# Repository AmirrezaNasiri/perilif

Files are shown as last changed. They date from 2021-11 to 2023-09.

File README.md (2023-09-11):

# Perilif: Period Pain Reliever 🌸

<p align="center">
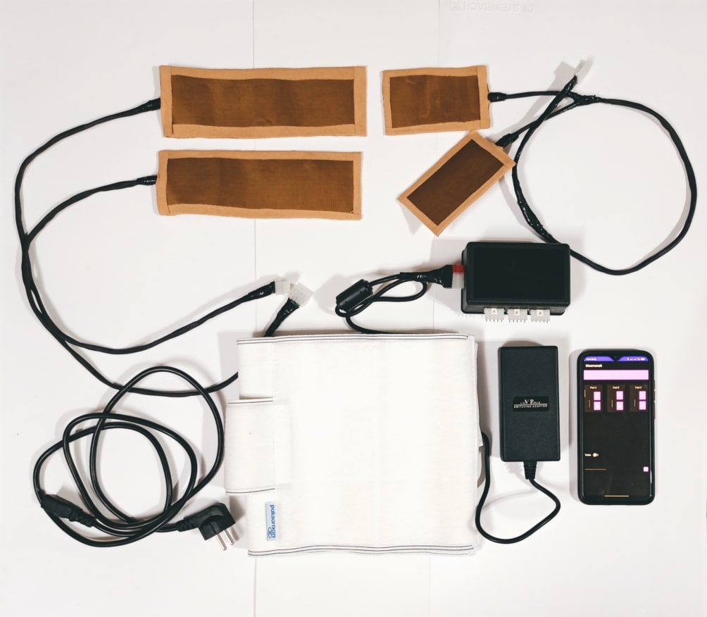
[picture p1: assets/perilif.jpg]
Perilif Image
  
</p>

Welcome to Perilif! This is a delightful, heat pad-based buddy designed to soothe menstrual cramps and IBS pain. Built with love on Arduino, it's paired with a cute Android app for easy control.

**Now, a little secret 🤫:** Perilif isn't meant for big-scale, real-life production. Think of it more like a DIY bestie for those curious minds out there. Sure, there are many high-tech gadgets you can buy, but if you fancy crafting something unique for yourself or a loved one, this is a fabulous place to start. 

## Stack 🛠️
Dive into the stack behind Perilif:

### Software

- **Kotlin** 📱:
  We've whipped up a nifty Android app using Kotlin. Connect and control your Perilif right from your phone, all thanks to the Bluetooth protocol.

  You can control each of the pads individually or turn the Turbo feature on to maximize the heat for a short period.

  The source code is available in the [android-app (kotlin)](android-app (kotlin)) directory.

<p align="center">
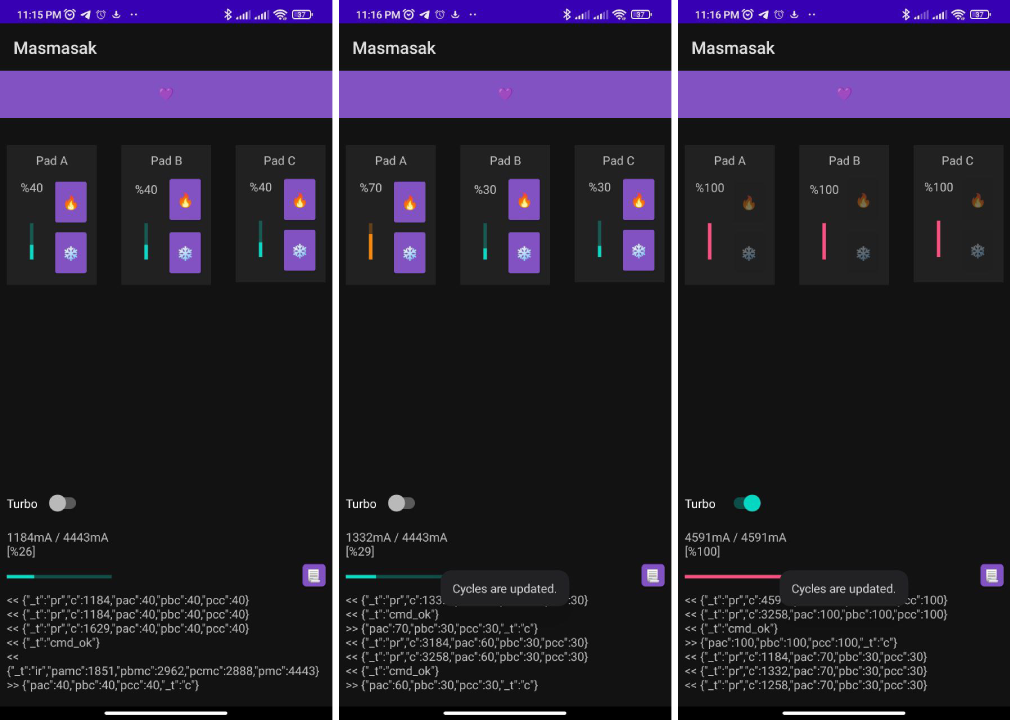
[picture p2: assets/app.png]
  
</p>

### Hardware
#### Components 🤖
- **Arduino Nano:**

  Using the nimble Arduino Nano, it’s the brain of our little device. It chirps via Bluetooth, keeps an eye on things, and makes sure the heat pads are just the right kind of cozy. PWM signals are the way it controls the heat level.

  The C++ source code of the Arduino project is available in [arduino-hardware (cpp)](arduino-hardware (cpp)) directory which can be opened inside Arduino IDE.

<p align="center">
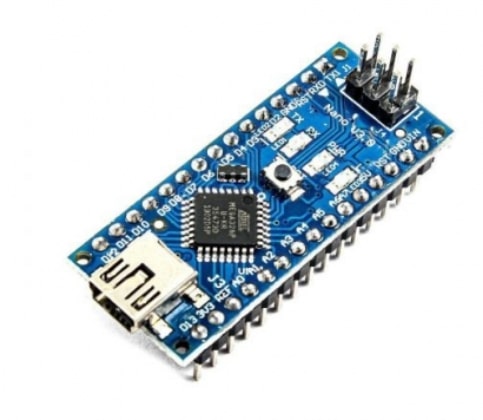
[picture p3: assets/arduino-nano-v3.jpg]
  
</p>

- **HC-05 Bluetooth Module:**

  An HC-05 Bluetooth module (with the helper board) is used for communicating with the Android app.

<p align="center">
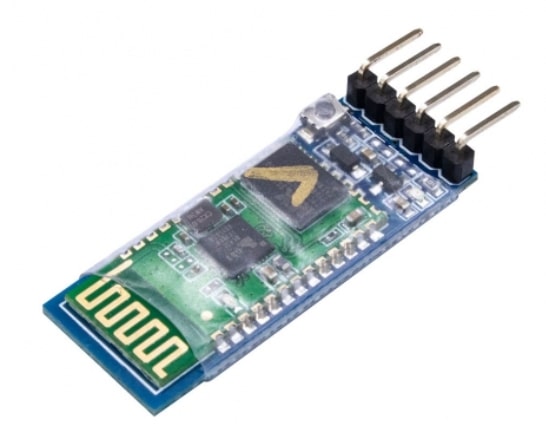
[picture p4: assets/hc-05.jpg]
  
</p>

- **Current Sensor:**

  A current sensor (ACS712) is used to gather initial power-source data and calibrate the application using that.

<p align="center">
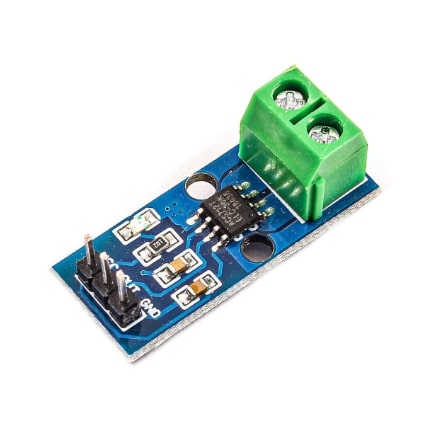
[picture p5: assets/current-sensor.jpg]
  
</p>

- **Power Supply (Adapter):**
  
  We used a reliable power supply that powers the device with 5V DC and 6A (max). 6A is required since we used 3 pads with 2A consumption.

  Since the device is not efficient with managing PWM signals, it can draw the total amount of current required by the heating pads. So with the current inefficient implementation, you need a reliable power supply.

<p align="center">
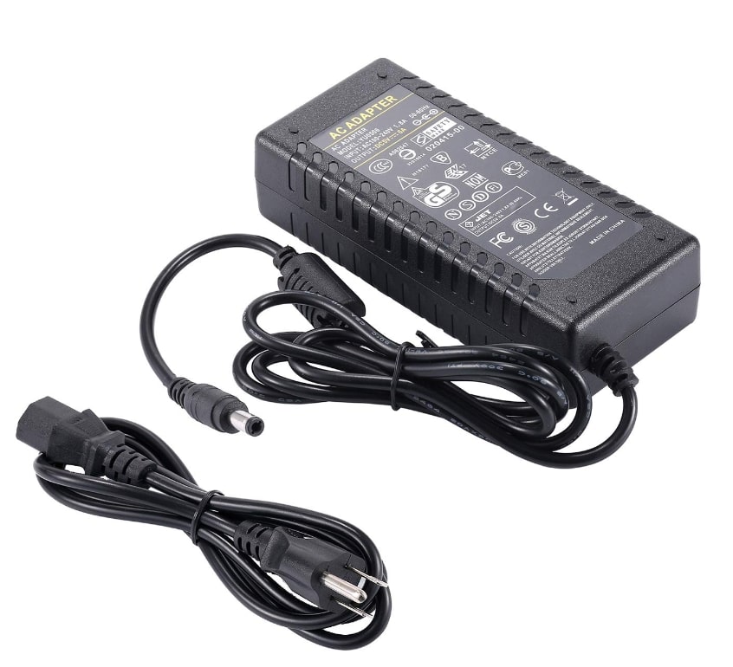
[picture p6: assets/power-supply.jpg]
  
</p>

- **MOSFETs:**

  For amplification, three MOSFETs (IRF3710) are responsible for controlling the current consumption of the heating pads by opening or closing their gate according to the received PWM signal.

  <p align="center">
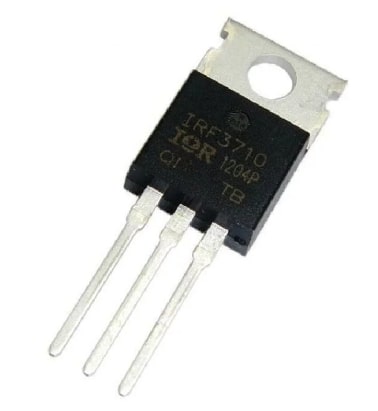
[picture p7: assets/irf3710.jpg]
    
  </p>

- **Heating Pads:**

  3 heating pads are used with the specification of a 3.7-5V operation range and 2A current consumption for each.
  
  <p align="center">
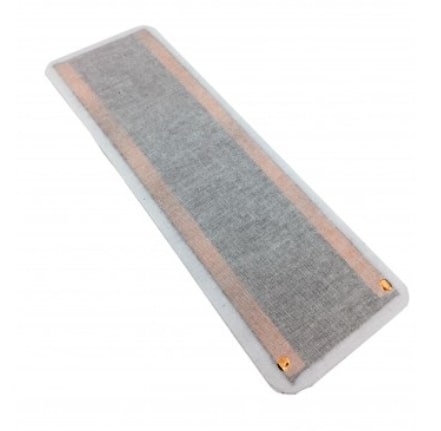
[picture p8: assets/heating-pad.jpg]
    
  </p>
  
  The heating pads are wrapped inside a fireproof fiber to reduce the contactable heat, then wrapped inside a bunch of Kinesio Elastic Therapeutic tapes to make them flexible and less annoying.

  <p align="center">
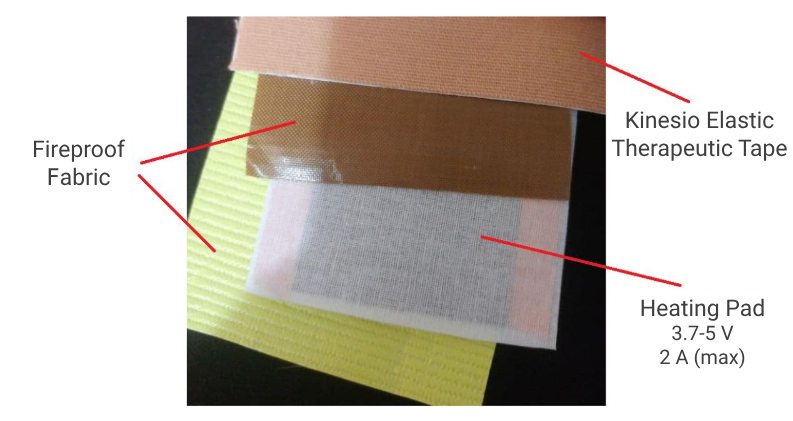
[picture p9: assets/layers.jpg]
    
  </p>

- **Case:**
  A combination of MOSFETs is also responsible for amplifying the PWM signals produced by the microcontroller to the heating pads.

  Here is an inner view of the plastic case:

  <p align="center">
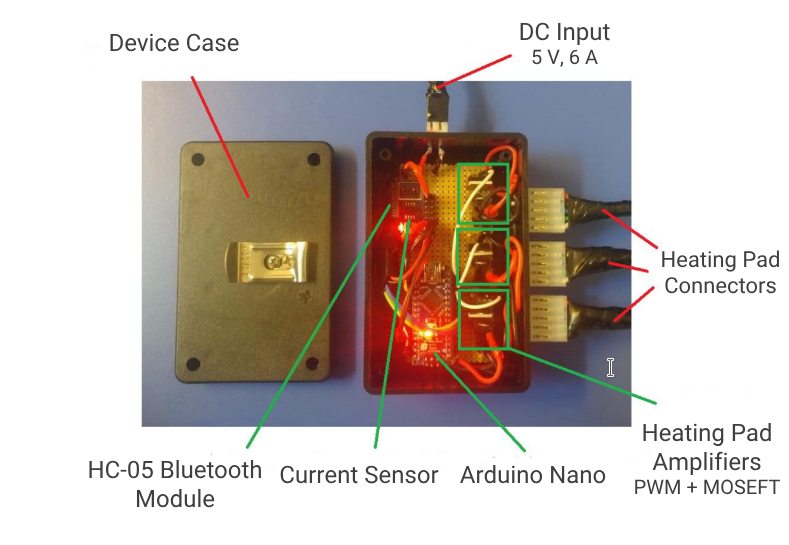
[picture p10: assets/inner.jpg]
    
  </p>

- **Back Brace:**

  A comfortable back brace to keep the heating pads in the place you need.

  <p align="center">
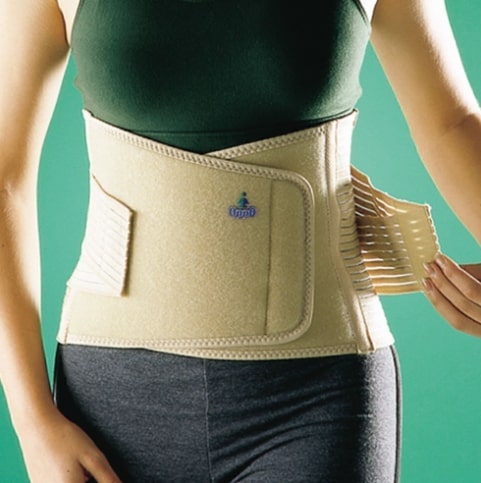
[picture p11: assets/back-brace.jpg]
    
  </p>

- **Wires, connectors, and soldering:**

  Heating pads require a high amount of current which requires proper and standard wires. Make sure that your wires can pass the required current without warming up (they do! so double-check the specifications).

  Same as the wires, all of your connectors must be able to pass the current too.

  If you're soldering on board, make sure the parts that are responsible for passing high currents are wide enough.

- **Other:**

  Just like any other project, we need a bunch of resistors (as described in the schematic), wire protectors, tapes, board, soldering iron, etc.

#### Schematic 🔧
  All those wires and thingamajigs? We've sketched them out using [Fritzing](https://fritzing.org/) (an open-source hardware initiative software). It's like a digital canvas, simple and fun to play around with.

  The fritzing source file is available in the [schematic (fritzing)](schematic (fritzing)) directory. Here is the schematic. Note that those Perilif Image indicate the heating pads.

<p align="center">
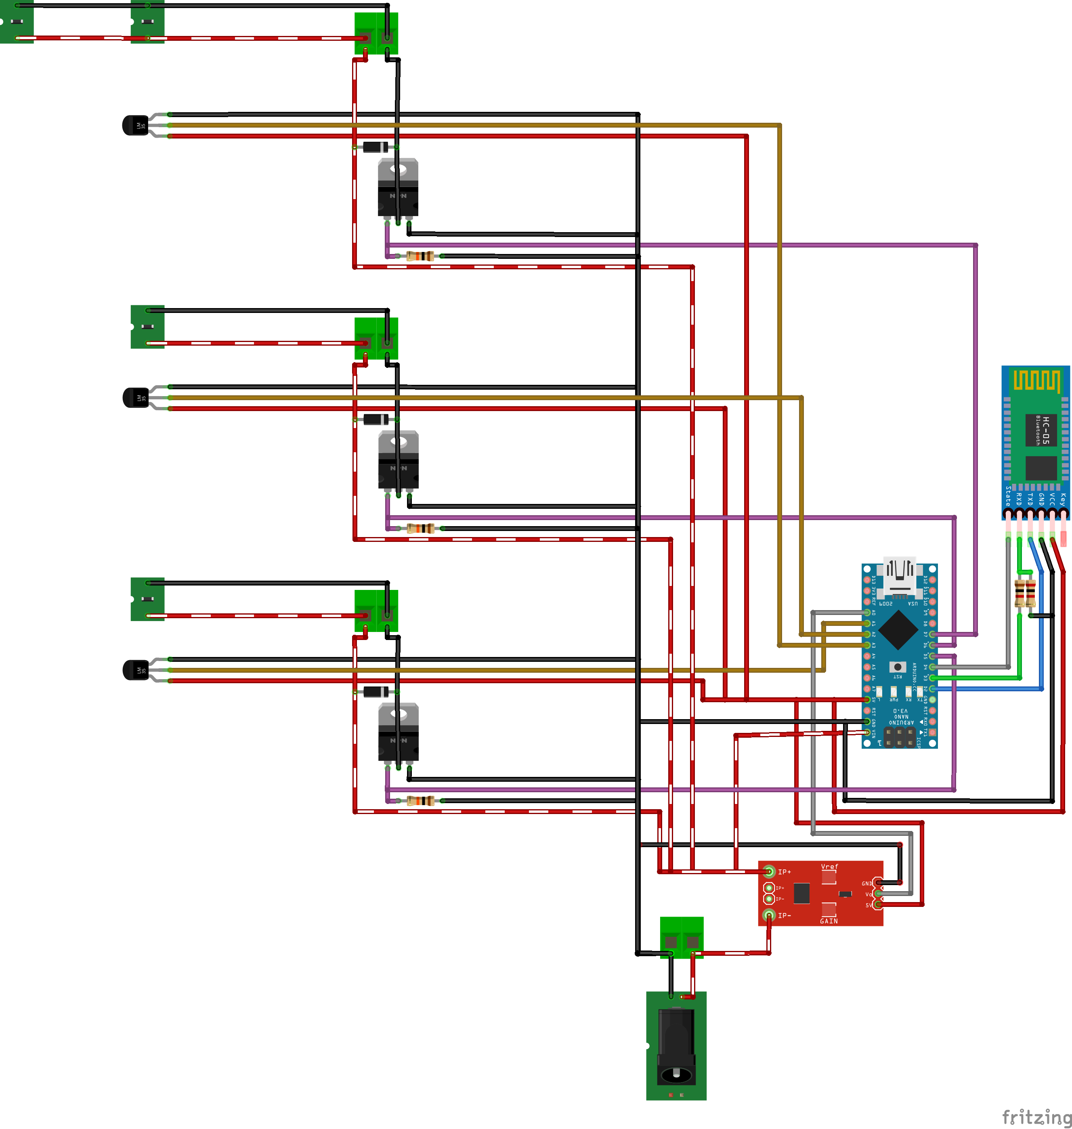
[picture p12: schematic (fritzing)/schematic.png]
  
</p>

## ⚠️ Important Notes and Known Issues
If you're going to build the device, use it, or contribute to improving it, consider the following notes very carefully:

### Bluetooth communication is not stable
Sometimes, you need to restart the device and/or the application to make Bluetooth communication possible. 

### Device must not be exposed to the body
Although the device is supplied with 5v (which is considered low), it can be still considered as not safe and must NOT be exposed to the body. Be very careful when building the device to make it less probable to make raw contact with the body.

Take note that the heat pads, tapes, fireproof fibers, casing, wiring, and other components used in this project must not be considered waterproof and must not be exposed directly to the body.

Direct contact with the body will lead to a small shock. For non-dry skin or open wounds, it's considered dangerous.

### Take care of fire hazard
Most parts of the device have the potential to get extremely warm. The heat pads, device case, components, the board inside, all of the wires, and the power supply can get heated very quickly.

Other than the PWM signals, NO mechanism is implemented to make the device safe, especially from warming up. If something gets hot, disconnect the device - wires are very potential.

### PWM signals are not implemented efficiently
Arduino uses PWM signals to order whether the heating pads should be off or not. In a control cycle, it may order all of the gates to open which will lead to high pressure on the power source.

In very rare cases it's needed to use all the power provided by the power source, but with the current design, it does happen a lot of times.

This way of implementation puts more unnecessary pressure on the power source which may lead to noise generation and reduction of the power-supply life.

### Amplifiers are not implemented efficiently
There are very considerable amount of energy wasted inside the device (in MOSFETs), instead of efficiently using it.

 This implementation leads to more-than-needed energy consumption to heat up the pads, heating the case and inner components, and reducing the device life.

## ⚠️ Strict Disclaimer

Before attempting to use or recreate the Perilif device or software, please read and understand the following disclaimer:

1. **Potential Injuries**: The Perilif device is a DIY project and, as such, has not undergone rigorous safety testing. Incorrect use or malfunctions can result in burns, electrical shocks, or other injuries. Always supervise the device while in use and NEVER sleep while it's operating.

2. **Fire Hazard**: The components, especially the heating pads, can become extremely hot and pose a risk of fire if they come into contact with flammable materials or malfunction. Ensure you're using the device in a safe environment.

3. **Electrical Safety**: While the device operates at 5V, which is considered low, it can still cause an electric shock or do injure, especially when in direct contact with the skin or if the skin is wet. Never expose any component of the device directly to your body.

4. **Medical Concerns**: If you have underlying medical conditions, consult with a healthcare professional before using the device. Continuous exposure to heat can exacerbate certain health issues.

5. **Liability**: The creators and contributors of Perilif will not be held responsible for any injuries, damages, or issues resulting from the use or misuse of the device or software. By choosing to use or recreate the Perilif, you acknowledge and accept all risks associated with it.

Always prioritize safety above all else and cease the use of the device at the first sign of malfunction or concern. If in doubt, please refrain from using it altogether.

Thanks for stopping by! Happy crafting and stay comfy! 😊❤️

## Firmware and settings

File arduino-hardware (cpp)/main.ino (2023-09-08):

#include <NeoSWSerial.h>
#include <ACS712.h>
#include <ArduinoJson.h>
#include <StreamUtils.h>

#define DEBUG false
#define BLUETOOTH_RX_PIN 2
#define BLUETOOTH_TX_PIN 3
#define BLUETOOTH_STATE_PIN 4
#define CURRENT_SENSOR_PIN A0
#define CURRENT_SENSOR_SENSITIVITY 66
#define PAD_A_PWM_PIN 9
#define PAD_B_PWM_PIN 10
#define PAD_C_PWM_PIN 11

NeoSWSerial bluetooth(BLUETOOTH_RX_PIN, BLUETOOTH_TX_PIN);
ACS712 current(CURRENT_SENSOR_PIN, 5.0, 1023, CURRENT_SENSOR_SENSITIVITY);

float lastCurrent;
int padA_Cycle, padB_Cycle, padC_Cycle = 0;

void setup() {
  if (DEBUG) {
    Serial.begin(74880);
    while (!Serial) continue;
  }

  current.autoMidPoint();
  
  pinMode(PAD_A_PWM_PIN, OUTPUT);
  pinMode(PAD_B_PWM_PIN, OUTPUT);
  pinMode(PAD_C_PWM_PIN, OUTPUT);

  log(F("[*] waiting for bluetooth connection ..."));

  pinMode(BLUETOOTH_STATE_PIN, INPUT);
  bluetooth.begin(9600);
  while (digitalRead(BLUETOOTH_STATE_PIN) == LOW) continue;

  sendSignal(F("ping"));
  sendInitialReport();
  delay(1000);
}

void loop() {
  processIncomingCommand();
  sendPeriodicReport();

  adjustPad(PAD_A_PWM_PIN, padA_Cycle);
  adjustPad(PAD_B_PWM_PIN, padB_Cycle);
  adjustPad(PAD_C_PWM_PIN, padC_Cycle);

  delay(1000);
}

void sendInitialReport() {
  log(F("[i] initial report:"));

  beginCurrentMeasuring();
  
  StaticJsonDocument<96> json;

  json[F("_t")] = F("ir");

  // Calculate max current of each pad
  adjustPad(PAD_A_PWM_PIN, 100);
  json[F("pamc")] = measureCurrent();
  adjustPad(PAD_A_PWM_PIN, 0);

  adjustPad(PAD_B_PWM_PIN, 100);
  json[F("pbmc")] = measureCurrent();
  adjustPad(PAD_B_PWM_PIN, 0);

  adjustPad(PAD_C_PWM_PIN, 100);
  json[F("pcmc")] = measureCurrent();
  adjustPad(PAD_C_PWM_PIN, 0);

  adjustPad(PAD_A_PWM_PIN, 100);
  adjustPad(PAD_B_PWM_PIN, 100);
  adjustPad(PAD_C_PWM_PIN, 100);
  delay(1000);
  json[F("pmc")] = measureCurrent();
  adjustPad(PAD_A_PWM_PIN, 0);
  adjustPad(PAD_B_PWM_PIN, 0);
  adjustPad(PAD_C_PWM_PIN, 0);

  sendJson(json);
}

void sendPeriodicReport() {
  log(F("[i] periodic report:"));

  StaticJsonDocument<192> json;

  json[F("_t")] = F("pr");
  json[F("c")] = getCurrent();
  json[F("pac")] = padA_Cycle;
  json[F("pbc")] = padB_Cycle;
  json[F("pcc")] = padC_Cycle;
  sendJson(json);
}

void processIncomingCommand() {
  if (bluetooth.available()) {
    log(F("[i] command received: "));
    
    StaticJsonDocument<64> json;

    #ifdef DEBUG
      ReadLoggingStream loggingStream(bluetooth, Serial);
      ReadBufferingStream bufferingStream(loggingStream, 64);
    #else
      ReadBufferingStream bufferingStream(bluetooth, 64);
    #endif

    DeserializationError error = deserializeJson(json, bufferingStream);
    
    if (error) {
      log(F("[-] error parsing json:"));
      log(error.f_str());
      sendSignal(F("cmd_err"));
      return;
    }
    
    if (json[F("_t")] == F("c")) {
      padA_Cycle = json[F("pac")].as<int>();
      padB_Cycle = json[F("pbc")].as<int>();
      padC_Cycle = json[F("pcc")].as<int>();
      sendSignal(F("cmd_ok"));
    } else {
      sendSignal(F("cmd_no"));
    }    
  }
}

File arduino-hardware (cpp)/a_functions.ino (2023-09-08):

void log(const char* message) {
  if (DEBUG) {
    Serial.println(message);
  }
}

void log(const __FlashStringHelper* message) {
  if (DEBUG) {
    Serial.println(message);
  }
}

void sendJson(const JsonDocument& doc) {
  if (DEBUG) {
    log(F("[i] sent to bluetooth:"));
    serializeJsonPretty(doc, Serial);
    Serial.println();
  }
  
  serializeJson(doc, bluetooth);
  bluetooth.println();
}

void sendSignal(const __FlashStringHelper* type) {
  StaticJsonDocument<32> doc;
  doc[F("_t")] = type;
  sendJson(doc);
}

void beginCurrentMeasuring() {
  lastCurrent = getCurrent();
}

float measureCurrent() {
  float value = getCurrent() - lastCurrent;
  return value > 0 ? value : 0;
}

float getCurrent() {
  delay(10);
  float value = current.mA_DC();
  return value > 0 ? value : 0;
}

void adjustPad(int pin, int value) {
  analogWrite(pin, (int) (value * 255 / 100));
}

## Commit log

2021-11-02 Add device info gatherer
2023-09-08 Restructure project and add arduino src
2023-09-09 Add schematic and readme
    [schematic.fzz]
